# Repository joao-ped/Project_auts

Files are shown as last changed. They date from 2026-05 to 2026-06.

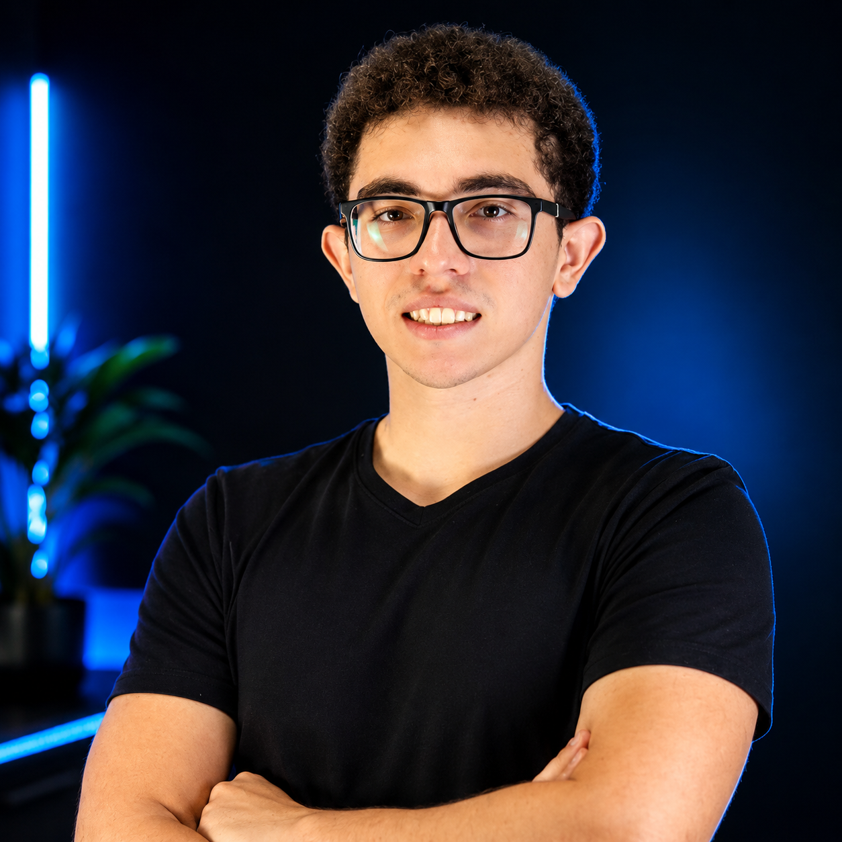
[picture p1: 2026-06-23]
img/Jao_ped.png

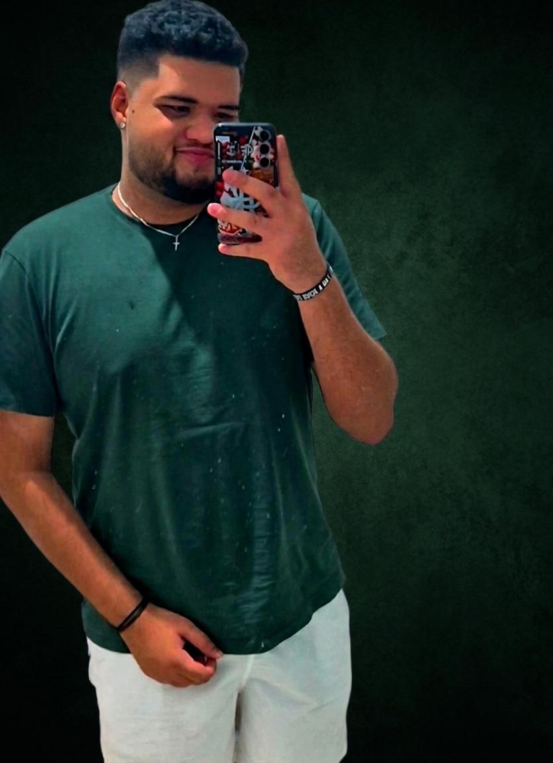
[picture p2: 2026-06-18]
img/Matheus.jpeg

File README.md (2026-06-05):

# Voz Autista v2.0 - Comunicador Assistivo

Dispositivo de comunicacao assistiva de baixo custo para pessoas com autismo que possuem dificuldade na comunicacao verbal. O usuario navega por categorias e palavras usando botoes coloridos, e o dispositivo reproduz o audio correspondente por um alto-falante.

Projeto desenvolvido com Arduino Uno, impressao 3D e componentes acessiveis.

**Site do projeto:** https://joao-ped.github.io/Project_auts/ (apos ativar Pages, veja secao abaixo)

---

## Hospedar no GitHub Pages (passo a passo)

O `index.html` na raiz funciona como pagina inicial e linka para todas as ferramentas. Para ativar:

1. Faca commit e push das mudancas (incluindo `index.html` e `.nojekyll`):
   ```bash
   git add index.html .nojekyll
   git commit -m "Adiciona site index.html + .nojekyll"
   git push origin main
   ```
2. No GitHub, va em **Settings -> Pages** do repositorio
3. Em **Source**, escolha **Deploy from a branch**
4. Em **Branch**, selecione `main` e pasta `/ (root)`, depois **Save**
5. Aguarde 1-2 min e acesse `https://joao-ped.github.io/Project_auts/`

> O arquivo `.nojekyll` (vazio) impede que o Jekyll processe o site - importante para que pastas como `wokwi_simulacao/` e arquivos com underscore funcionem.

Links que ficarao online:
- `/` -> hub (index.html)
- `/apresentacao.html` -> slides
- `/manual_montagem_visual.html` -> manual
- `/simulador.html` -> simulador no navegador
- `/wokwi_simulacao/abrir_no_wokwi.html` -> assistente Wokwi
- `/case_3d/visualizar_case_3d.html` -> viewer 3D

---

## Funcionalidades

- **7 categorias com 35 palavras** - Necessidades, Sentimentos, Acoes, Comidas, Lugares, Pessoas, Saude
- **Frases compostas** - Empilhe ate 5 palavras e fale de uma vez (ex: "Eu quero" + "Beber" + "Agua")
- **Controle de volume** - Potenciometro analogico com ajuste em tempo real
- **Monitoramento de bateria** - Icone no LCD (18650 recarregavel via USB)
- **Feedback tatil** - Motor de vibracao confirma cada acao
- **Modo sleep** - LCD apaga apos 2 min de inatividade para economizar bateria
- **Auto-deteccao I2C** - Funciona com diferentes modulos LCD sem alterar codigo
- **Configuracao facil** - Secao dedicada no codigo para personalizar categorias e palavras

## Como funciona

| Botao | Cor | Funcao |
|---|-----|---|
| Cat+ | Vermelho | Avanca categoria |
| Cat- | Amarelo | Volta categoria |
| Pal+ | Verde | Avanca palavra |
| Pal- | Azul | Volta palavra |
| FALAR | Preto | Press curto = fala / Press longo = adiciona a frase |
| Cat+ & Cat- | Vermelho + Amarelo | Fala a frase composta |
| Pal+ & Pal- | Verde + Azul | Limpa a frase |

## Hardware

### Lista de materiais principais

| Componente | Funcao |
|---|---|
| Arduino Uno R3 | Microcontrolador |
| LCD 16x2 I2C | Display de navegacao |
| DFPlayer Mini + microSD | Reproducao de audio MP3 |
| Alto-falante 8ohm 2W | Saida de som |
| 5x Botoes 12mm (coloridos) | Navegacao e fala |
| Potenciometro 10k linear | Ajuste de volume |
| Motor vibracao coin 10mm | Feedback tatil |
| Transistor 2N2222 + Diodo 1N4148 | Driver do motor |
| Bateria 18650 + Modulo TP4056 | Alimentacao portatil recarregavel |
| Chave deslizante | Liga/Desliga |
| Case impresso 3D | Caixa do dispositivo |

### Pinagem do Arduino

```
D2  -> Botao Vermelho (Cat+)     D10 <- DFPlayer TX
D3  -> Botao Amarelo  (Cat-)     D11 -> 1k -> DFPlayer RX
D4  -> Botao Verde    (Pal+)     A0  <- Potenciometro (volume)
D5  -> Botao Azul     (Pal-)     A1  <- Divisor tensao (bateria)
D6  -> Botao Preto    (FALAR)    A4  -> LCD SDA (I2C)
D7  -> Transistor -> Motor vib.  A5  -> LCD SCL (I2C)
```

### Custo estimado

O custo total dos componentes fica em torno de **~R$ 128**, dependendo do fornecedor. Componentes mais caros: Arduino (~R$35), bateria 18650 (~R$15), LCD I2C (~R$15), impressao 3D (~R$15), DFPlayer (~R$12).

## Estrutura do projeto

```
Project_auts/
|-- voz_autista_maker_code.ino    # Codigo principal (hardware real)
|-- GUIA_IMPLEMENTACAO.md         # Guia completo de montagem e uso
|-- manual_montagem_visual.html   # Manual visual com diagramas SVG interativos
|-- case_3d/
|   |-- case_voz_autista.scad     # Case 3D parametrico (OpenSCAD)
|   |-- exportar_base.scad        # Exportar apenas a base do case
|   |-- exportar_tampa.scad       # Exportar apenas a tampa do case
|   |-- visualizar_case_3d.html   # Visualizador 3D interativo no navegador
|-- wokwi_simulacao/
|   |-- sketch.ino                # Codigo adaptado para simulacao
|   |-- diagram.json              # Circuito do simulador Wokwi
|   |-- wokwi.toml                # Configuracao do Wokwi
|   |-- COMO_USAR.md              # Instrucoes da simulacao
|-- Apresentacao_Voz_Autista.pptx       # Apresentacao v1
|-- Apresentacao_Voz_Autista_v2.pptx    # Apresentacao v2
```

## Simulacao (sem hardware)

O projeto pode ser testado integralmente no simulador **Wokwi** sem precisar de nenhum componente fisico:

1. Acesse [wokwi.com](https://wokwi.com)
2. Crie um novo projeto Arduino Uno
3. Cole o conteudo de `wokwi_simulacao/sketch.ino` no editor
4. Cole o conteudo de `wokwi_simulacao/diagram.json` na aba diagram.json
5. Clique em Play

Na simulacao, o DFPlayer e substituido por um buzzer e o motor de vibracao por um LED verde.

## Cartao SD (hardware real)

Formato: **FAT32** | 7 pastas | 35 arquivos MP3 (voz clara, 1-3s cada)

```
/01/ Necessidades   001.mp3="Eu quero"  002.mp3="Comer"  003.mp3="Beber"  004.mp3="Banheiro"  005.mp3="Dormir"
/02/ Sentimentos    001.mp3="Feliz"     002.mp3="Triste" 003.mp3="Bravo"  004.mp3="Calmo"     005.mp3="Medo"
/03/ Acoes          001.mp3="Brincar"   002.mp3="Ajuda"  003.mp3="Sair"   004.mp3="Parar"     005.mp3="Ir"
/04/ Comidas        001.mp3="Agua"      002.mp3="Suco"   003.mp3="Leite"  004.mp3="Pao"       005.mp3="Fruta"
/05/ Lugares        001.mp3="Casa"      002.mp3="Escola" 003.mp3="Parque" 004.mp3="Medico"    005.mp3="Banho"
/06/ Pessoas        001.mp3="Mamae"     002.mp3="Papai"  003.mp3="Vovo"   004.mp3="Professor" 005.mp3="Amigo"
/07/ Saude          001.mp3="Doi"       002.mp3="Enjoo"  003.mp3="Frio"   004.mp3="Calor"     005.mp3="Cansado"
```

## Case 3D

O case foi projetado em **OpenSCAD** com parametros editaveis. Dimensoes: 170x110x42mm.

- Abra `case_3d/case_voz_autista.scad` no [OpenSCAD](https://openscad.org)
- Ou visualize no navegador abrindo `case_3d/visualizar_case_3d.html`
- Material recomendado: PLA ou PETG

Inclui: berco para bateria 18650, furos para botoes, janela do LCD, grade do alto-falante, abertura para USB/SD/volume/chave.

## Dependencias (Arduino IDE)

Instalar via **Ferramentas > Gerenciar Bibliotecas**:

- `LiquidCrystal_I2C` (por Frank de Brabander)
- `DFRobotDFPlayerMini` (por DFRobot)

## Autonomia

- Bateria 18650 (2600mAh tipica)
- Consumo medio: ~80mA (uso intermitente)
- Autonomia estimada: **~30 horas**

## Licenca

Projeto de codigo aberto para fins educacionais e assistivos.

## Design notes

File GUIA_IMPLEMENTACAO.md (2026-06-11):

# Voz Autista v3.0 - Guia de Implementacao Completo

**Comunicador Assistivo para Pessoas com Autismo**

Versao: 3.0 | Atualizado: Junho 2026

---

## Indice

1. [Visao Geral do Projeto](#1-visao-geral-do-projeto)
2. [Lista de Materiais (BOM)](#2-lista-de-materiais-bom)
3. [Tabela de Pinagem](#3-tabela-de-pinagem)
4. [Esquema de Ligacoes](#4-esquema-de-ligacoes)
5. [Circuito do Motor de Vibracao](#5-circuito-do-motor-de-vibracao)
6. [Circuito de Monitoramento de Bateria](#6-circuito-de-monitoramento-de-bateria)
7. [Estrutura do Cartao SD](#7-estrutura-do-cartao-sd)
8. [Funcionalidades](#8-funcionalidades)
9. [Montagem Passo a Passo (case v3.0)](#9-montagem-passo-a-passo-case-v30)
10. [Upload do Codigo](#10-upload-do-codigo)
11. [Configuracao Facil](#11-configuracao-facil)
12. [Como Usar](#12-como-usar)
13. [Resolucao de Problemas](#13-resolucao-de-problemas)
14. [Notas Tecnicas](#14-notas-tecnicas)

---

## 1. Visao Geral do Projeto

O **Voz Autista** e um dispositivo de comunicacao assistiva (AAC) de baixo custo
(~R$128) para pessoas autistas nao-verbais ou com comunicacao verbal limitada.
O usuario navega por 7 categorias x 5 palavras com botoes coloridos e o
dispositivo reproduz o audio MP3 correspondente.

### O que mudou da v2.0 para a v3.0

**A pinagem dos botoes, LCD, DFPlayer, volume e vibracao NAO mudou.**
As mudancas sao de circuito (valores e fios novos) e de case:

| Mudanca | Por que |
|---|---|
| Divisor da bateria: **10k+10k -> 100k+33k** + capacitor 100nF em A1, lido com a **referencia interna de 1.1V** | Com a 18650 alimentando o Arduino, o VCC *e* a tensao da bateria - medir Vbat/2 contra o proprio VCC dava leitura constante (bug). A referencia interna e absoluta. Bonus: o dreno cai de ~210uA para ~32uA |
| RX do DFPlayer: resistor 1k -> **divisor 1k/2k** | O DFPlayer e logica 3.3V; o divisor entrega 3.3V limpos (recomendacao do datasheet DFR0299) |
| **Capacitor 470uF + 100nF** no VCC/GND do DFPlayer | O modulo tem picos de corrente no inicio de cada faixa que causavam resets/cliques |
| **Fio novo: BUSY do DFPlayer -> D8** | A frase composta espera o MP3 terminar de verdade, em vez de pausa fixa de 1.3s |
| **Boost MT3608** entre a chave e o rail 5V | A 18650 (3.0-4.2V) direto no 5V roda o ATmega fora de spec e deixa o LCD com contraste fraco. O boost entrega 5V estaveis |
| Case v3.0 em cunha, botoes 2+2+1, bateria com tampa de troca | Ver `case_3d/CHANGELOG_V3.md` |

---

## 2. Lista de Materiais (BOM)

| Qtd | Componente | Especificacao | Funcao |
|-----|---|---|---|
| 1 | Arduino Uno R3 | ATmega328P | Microcontrolador principal |
| 1 | LCD 16x2 com modulo I2C | Endereco auto-detectado (0x27/0x3F/0x20/0x38) | Display para navegacao |
| 1 | DFPlayer Mini MP3 | Modulo MP3 com slot microSD | Reproducao de audio |
| 1 | Alto-falante | 8 ohm, 2W, 40mm | Saida de audio |
| 1 | Botao momentaneo 12mm | **Vermelho** | Categoria + (avancar) |
| 1 | Botao momentaneo 12mm | **Amarelo** | Categoria - (voltar) |
| 1 | Botao momentaneo 12mm | **Verde** | Palavra + (avancar) |
| 1 | Botao momentaneo 12mm | **Azul** | Palavra - (voltar) |
| 1 | Botao momentaneo 12mm | **Preto** | FALAR (reproducao) |
| 1 | Resistor 1k ohm | 1/4W | D11 -> RX DFPlayer (perna de cima do divisor) |
| 1 | Resistor 2k ohm | 1/4W | **v3.0** RX DFPlayer -> GND (perna de baixo) |
| 1 | Capacitor eletrolitico 470uF | >= 10V | **v3.0** VCC/GND do DFPlayer (anti-reset) |
| 2 | Capacitor ceramico 100nF | -- | **v3.0** 1x DFPlayer VCC, 1x pino A1 |
| 1 | Potenciometro 10k ohm | Linear (B10K) | Ajuste de volume |
| 1 | Motor de vibracao coin | 10mm, 3-5V | Feedback tatil |
| 1 | Transistor NPN 2N2222 | TO-92 | Driver do motor de vibracao |
| 1 | Diodo 1N4148 | Diodo de sinal | Protecao flyback do motor |
| 1 | Resistor 1k ohm | 1/4W | Base do transistor 2N2222 |
| 1 | Resistor 100k ohm | 1/4W | **v3.0** Divisor da bateria (substitui 10k) |
| 1 | Resistor 33k ohm | 1/4W | **v3.0** Divisor da bateria (substitui 10k) |
| 1 | Bateria 18650 | 3.7V recarregavel | Alimentacao portatil |
| 1 | Modulo TP4056 | Carregador Li-Ion com protecao (DW01A) | Carga via micro-USB |
| 1 | Modulo boost MT3608 | Ajustado para 5.0V | **v3.0** Rail 5V estavel a partir da 18650 |
| 1 | Chave deslizante | 2 posicoes | Liga/Desliga geral |
| 1 | Cartao microSD | FAT32, ate 32GB | Armazenamento dos audios MP3 |
| -- | Fios jumper | Macho-macho e macho-femea | Conexoes |
| 1 | Case impresso 3D v3.0 | Pasta `/case_3d/` (base + tampa + tampa bateria) | Caixa do dispositivo |

**Nota sobre os botoes:** ligados com pull-up interno (INPUT_PULLUP); cada botao
conecta o pino ao GND. Nao precisa resistor externo.

---

## 3. Tabela de Pinagem

| Pino | Componente | Conexao | Observacao |
|---|---|---|---|
| D2 | Botao Vermelho (Cat+) | Botao para GND | INPUT_PULLUP interno |
| D3 | Botao Amarelo (Cat-) | Botao para GND | INPUT_PULLUP interno |
| D4 | Botao Verde (Pal+) | Botao para GND | INPUT_PULLUP interno |
| D5 | Botao Azul (Pal-) | Botao para GND | INPUT_PULLUP interno |
| D6 | Botao Preto (FALAR) | Botao para GND | INPUT_PULLUP interno |
| D7 | Motor vibracao | Via 1k -> base 2N2222 | Flyback 1N4148 no motor |
| **D8** | **DFPlayer BUSY** | **BUSY -> D8 direto** | **NOVO v3.0** - LOW = tocando |
| D10 | DFPlayer TX | TX -> D10 | SoftwareSerial RX |
| D11 | DFPlayer RX | D11 -> 1k -> RX; RX -> 2k -> GND | **ATUALIZADO v3.0** divisor 3.3V |
| A0 | Potenciometro volume | Wiper (centro) | 0-1023 -> volume 0-30 |
| A1 | Divisor da bateria | Juncao 100k (Vbat) / 33k (GND) + 100nF | **ATUALIZADO v3.0** ref interna 1.1V |
| A4 | LCD SDA | Modulo I2C | Barramento I2C dados |
| A5 | LCD SCL | Modulo I2C | Barramento I2C clock |

Pinos livres para expansao: D9, D12, D13, A2, A3.

### Diagrama de pinos do Arduino

```
                     +-----[USB]-----+
                     |               |
                D13 -|               |- D12
                3.3V-|               |- D11 ---> 1k ---> DFPlayer RX ---> 2k ---> GND
                AREF-|               |- D10 <--- DFPlayer TX
 [POT volume]--> A0 -|    ARDUINO    |- D9
 [BAT 100k/33k]> A1 -|     UNO R3    |- D8  <--- DFPlayer BUSY        [NOVO v3.0]
                 A2 -|               |- D7  ---> 1k ---> Base 2N2222
                 A3 -|               |- D6  <--- Botao Preto  (FALAR)
   [LCD SDA] --> A4 -|               |- D5  <--- Botao Azul   (Pal-)
   [LCD SCL] --> A5 -|               |- D4  <--- Botao Verde  (Pal+)
                     |               |- D3  <--- Botao Amarelo(Cat-)
                     |               |- D2  <--- Botao Vermelho(Cat+)
                 5V -|               |- GND
                GND -|               |- GND
                VIN -|               |
                     +---------------+
```

---

## 4. Esquema de Ligacoes

### 4.1 Botoes (todos iguais)

```
Pino Dx ----+---- [Botao] ---- GND
            |
        (pull-up interno ativado por software)
```

| Botao | Cor | Pino | Posicao no case v3.0 |
|---|-----|---|---|
| CAT- | Amarelo | D3 | Fileira de cima, esquerda (simbolo "v") |
| CAT+ | Vermelho | D2 | Fileira de cima, direita (simbolo "^") |
| PAL- | Azul | D5 | Fileira do meio, esquerda (simbolo "<") |
| PAL+ | Verde | D4 | Fileira do meio, direita (simbolo ">") |
| FALAR | Preto | D6 | Embaixo, central, anel maior (balao de fala) |

### 4.2 DFPlayer Mini (ATUALIZADO v3.0)

```
                      +----------+
            D10 <---- | TX       |
 D11 --[1k]--+------> | RX       |     <- divisor 1k/2k: nivel 3.3V
             |        |          |
           [2k]       | VCC -----+--- 5V  (+ 470uF e 100nF para o GND,
             |        |          |         o mais perto possivel do modulo)
            GND       | GND -----+--- GND
                      | SPK1 ----+--- Alto-falante 8ohm 2W (+)
                      | SPK2 ----+--- Alto-falante 8ohm 2W (-)
                      | BUSY ----+--> D8   [NOVO v3.0: LOW = tocando]
                      | SD slot  |  <- microSD FAT32
                      +----------+
```

**Importante:** o eletrolitico de 470uF evita resets do DFPlayer nos picos de
corrente do inicio de cada faixa. Observe a polaridade (perna maior no VCC).

### 4.3 LCD 16x2 I2C

```
  VCC -> 5V | GND -> GND | SDA -> A4 | SCL -> A5
```

### 4.4 Potenciometro de Volume

```
  5V ---[Terminal 1]   A0 ---[Wiper]   GND ---[Terminal 3]
```

### 4.5 Alimentacao completa (ATUALIZADO v3.0)

```
  [Bateria 18650] --- B+/B- --- [TP4056 c/ protecao] --- OUT+ ---[Chave]--- IN+ [MT3608] OUT+ --- 5V do Arduino,
                                       |                                        (ajustado     LCD, DFPlayer, pot,
                                      OUT- ------------------------------------- p/ 5.0V)     motor (rail 5V comum)
                                       |
                                      GND comum (Arduino + LCD + DFPlayer + divisor + emissor 2N2222)
```

**Antes de conectar o Arduino:** alimente o MT3608 e gire o trimpot ate medir
**5.0V** na saida com multimetro. So depois ligue o rail.

**Por que o boost?** A 18650 entrega 3.0-4.2V. Direto no pino 5V, o ATmega328
roda 16MHz abaixo do minimo de 4.5V do datasheet e o LCD HD44780 perde
contraste. O MT3608 (~R$5) resolve os dois problemas e ainda da volume cheio
ao DFPlayer.

---

## 5. Circuito do Motor de Vibracao

(Sem mudancas eletricas na v3.0 - apenas documentacao revisada.)

```
            +5V ----+-------------+
                    |             |
               [Motor coin]   [1N4148]   <- catodo (faixa) no +5V
                    |             |
                    +------+------+
                           |
                       Coletor (C)
                        2N2222          Base (B) --- [1k] --- D7
                       Emissor (E)
                           |
                          GND
```

- Ib = (5 - 0.7) / 1k ~ 4.3mA -> beta forcado ~19 para 80mA: saturacao garantida
- O 1N4148 fica em **antiparalelo com o motor**: catodo (faixa) no +5V, anodo no coletor
- Pinagem do 2N2222 (TO-92, face plana para voce): **E - B - C**

---

## 6. Circuito de Monitoramento de Bateria (ATUALIZADO v3.0)

```
  Bateria (+) -----[R1 = 100k]-----+----------- A1 (Arduino)
                                   |       |
                              [R2 = 33k] [100nF]
                                   |       |
                                  GND     GND
```

### Como funciona (v3.0)

- O divisor entrega `Vbat x 33/133` em A1: 4.2V -> 1.042V; 3.0V -> 0.744V
- O codigo le A1 contra a **referencia interna de 1.1V** (`analogReference(INTERNAL)`),
  que e absoluta - nao depende do VCC variavel da bateria
- ADC ~969 = 100% | ADC ~692 = 0%
- O capacitor de 100nF em A1 compensa a impedancia alta do divisor para o
  sample-and-hold do ADC (fonte: datasheet ATmega328, secao ADC, impedancia
  de fonte recomendada <= 10k)
- Dreno permanente do divisor: ~32uA (era ~210uA com 10k+10k)

> **Atencao:** nao reutilize os resistores de 10k da v2.0 neste divisor - o
> firmware v3.0 espera 100k/33k. Se mudar os valores, recalcule os limites
> 692/969 em `readBattery()`.

---

## 7. Estrutura do Cartao SD

O cartao microSD deve ser formatado em **FAT32**. Sao **7 categorias** com
**5 palavras** cada (35 MP3s):

```
microSD (FAT32)
├── /01/ Necessidades: 001 "Eu quero", 002 "Comer", 003 "Beber", 004 "Banheiro", 005 "Dormir"
├── /02/ Sentimentos:  001 "Feliz", 002 "Triste", 003 "Bravo", 004 "Calmo", 005 "Medo"
├── /03/ Acoes:        001 "Brincar", 002 "Ajuda", 003 "Sair", 004 "Parar", 005 "Ir"
├── /04/ Comidas:      001 "Agua", 002 "Suco", 003 "Leite", 004 "Pao", 005 "Fruta"
├── /05/ Lugares:      001 "Casa", 002 "Escola", 003 "Parque", 004 "Medico", 005 "Banho"
├── /06/ Pessoas:      001 "Mamae", 002 "Papai", 003 "Vovo", 004 "Professor", 005 "Amigo"
└── /07/ Saude:        001 "Doi", 002 "Enjoo", 003 "Frio", 004 "Calor", 005 "Cansado"
```

- Pastas exatamente `01`..`07`; arquivos exatamente `001.mp3`..`005.mp3`
- 44100 Hz, 128 kbps, mono; 1-3 segundos por palavra
- Nao deixe outros arquivos na raiz do cartao

---

## 8. Funcionalidades

### 8.1 Volume por potenciometro (A0)
Leitura a cada 500ms, mapeada para 0-30 e enviada ao DFPlayer.

### 8.2 Auto-deteccao I2C do LCD
Escaneia `0x27`, `0x3F`, `0x20`, `0x38` na inicializacao.

### 8.3 Monitoramento de bateria (A1) - v3.0
Divisor 100k/33k + referencia interna 1.1V (secao 6). Icone no LCD a cada 10s.

### 8.4 Frase composta + fim de audio real (v3.0)

| Acao | Como fazer | Resultado |
|---|---|---|
| Falar palavra | Press **curto** no FALAR | Reproduz o audio |
| Adicionar a frase | Press **longo** no FALAR (>800ms) | Palavra entra no buffer (ate 5) |
| Falar frase | **Cat+ e Cat- juntos** | Fala a sequencia toda |
| Limpar frase | **Pal+ e Pal- juntos** | Esvazia o buffer |

**v3.0:** entre as palavras da frase, o firmware espera o pino **BUSY (D8)**
subir (fim real do MP3) + 250ms de pausa, em vez do delay fixo de 1.3s.
Frases soam naturais com audios de qualquer duracao.

### 8.5 Vibracao (D7)
Motor coin via 2N2222; 60ms a cada acao de botao.

### 8.6 Sleep
LCD apaga apos 2 min sem uso; qualquer botao acorda.

### 8.7 Configuracao facil
Secao demarcada no `.ino` para editar categorias, palavras e tempos.

---

## 9. Montagem Passo a Passo (case v3.0)

> Imprima primeiro: `exportar_base.scad`, `exportar_tampa.scad` e
> `exportar_tampa_bateria.scad` (que inclui o knob do potenciometro e o
> adaptador do botao FALAR). Encaixe tudo A SECO antes de soldar.

### Passo 1: Eletronica de potencia (fora do case)
1. Solde fios na 18650 (ou use suporte com fios) -> B+/B- do TP4056
2. TP4056 OUT+ -> chave deslizante -> IN+ do MT3608; OUT-/GND comum
3. Alimente e ajuste o trimpot do MT3608 ate **5.0V** na saida
4. So entao conecte OUT+ do MT3608 ao pino **5V** do Arduino

### Passo 2: Perfboard do driver e divisores
Em uma perfboard pequena (~20x10mm), monte:
1. 2N2222 + resistor 1k de base + 1N4148 (catodo p/ +5V)
2. Divisor da bateria: 100k (Vbat -> A1) + 33k (A1 -> GND) + 100nF (A1 -> GND)
3. Divisor do DFPlayer: 1k (D11 -> RX) + 2k (RX -> GND)
4. 470uF + 100nF entre VCC e GND do DFPlayer (perto do modulo)

### Passo 3: Fixar na base impressa
1. **Arduino** nos 4 pilares M2.5 (canto esquerdo; USB-B e jack saem pela esquerda)
2. **TP4056** nos clipes (parede esquerda; micro-USB pela abertura)
3. **MT3608** e **perfboard** nos cantos de retencao (fundo esquerdo/tras)
4. **DFPlayer** nos clipes (canto traseiro direito; slot SD pela parede traseira)
5. **Alto-falante** no fundo, ima para cima, borda sob os 3 postes com labio
   (o som sai pela grade no fundo do case)
6. **Motor coin** no suporte anelar (fio pela abertura lateral do anel)
7. **Chave** na moldura recuada da parede traseira (cola quente por dentro)
8. **Potenciometro** no furo da parede direita (porca por fora) + knob impresso

### Passo 4: Botoes na tampa (layout 2+2+1)
1. De cima para baixo: CAT- (amarelo) / CAT+ (vermelho), PAL- (azul) /
   PAL+ (verde), FALAR (preto) embaixo no centro
2. Cada furo tem anel tatil em relevo e canaleta para pintura/anel colorido
3. Pressione o **adaptador Ø18 impresso** sobre o cap do botao preto (FALAR)
4. **LCD**: por dentro da tampa, na face inclinada - 4 parafusos M3
   auto-atarraxantes nos bosses (janela 73x26 para a area visivel)

### Passo 5: Bateria e fechamento
1. Passe o cordao (se for usar) pelas orelhas traseiras (furos de 4mm)
2. Encaixe a tampa (saia interna sobre o rim da base, bumps de clique)
3. 2 parafusos M3: um na frente-direita, um atras-centro
4. Insira a 18650 pelo **fundo** (tampa da bateria com 2 clipes) -
   observe os simbolos +/- em relevo na propria tampa
5. Cole os 4 pes de borracha nos rebaixos do fundo

---

## 10. Upload do Codigo

- Arduino IDE 1.8.x ou 2.x
- Bibliotecas: `LiquidCrystal_I2C` (Frank de Brabander) e
  `DFRobotDFPlayerMini` (DFRobot)
- Placa: Arduino Uno; abra `voz_autista_maker_code.ino` e faca Upload
- O USB-B fica acessivel pela lateral esquerda do case - nao precisa abrir

---

## 11. Configuracao Facil

Edite a secao demarcada no `.ino` (categorias, palavras, tempos).
Detalhes na secao 11 do guia v2.0 permanecem validos; os tempos agora incluem:

```cpp
const int PHRASE_DELAY = 250;  // pausa APOS o fim real do audio (BUSY/D8)
```

---

## 12. Como Usar

1. **Ligar:** chave na posicao ON (recuada na traseira - empurre com a unha)
2. Navegue categorias (fileira de cima) e palavras (fileira do meio)
3. **FALAR** (botao grande de baixo): curto = fala; longo = adiciona a frase
4. Volume: knob estriado na lateral direita
5. Recarga: cabo micro-USB na lateral esquerda (LED vermelho = carregando,
   azul/verde = completo)
6. Troca de bateria: tampa com clipes no fundo - sem abrir o case

---

## 13. Resolucao de Problemas

| Problema | Causa Provavel | Solucao |
|---|---|---|
| LCD nao liga / tela em branco | I2C nao detectado | Verifique SDA (A4) e SCL (A5); ajuste o trimpot de contraste do backpack |
| LCD com contraste fraco mesmo ajustando | Alimentacao abaixo de 5V | Confira a saida do MT3608 (deve ser 5.0V); bateria carregada? |
| DFPlayer nao reproduz | SD em formato errado | FAT32; pastas /01/../07/; arquivos 001.mp3..005.mp3 |
| DFPlayer reseta/clica ao tocar | Falta decoupling | Confirme o 470uF + 100nF no VCC do modulo (470uF com polaridade certa) |
| Frase composta "atropela" as palavras | Fio BUSY solto | Confira BUSY -> D8 (o firmware usa timeout de 8s como fallback) |
| Medidor de bateria nao muda | Divisor errado | Confirme 100k (Vbat->A1) e 33k (A1->GND); meca A1: deve dar Vbat x 0.248 |
| Medidor de bateria sempre cheio/vazio | Resistores trocados entre si | 100k vai no lado da bateria, 33k no lado do GND |
| Volume nao muda | Pot desconectado | 3 fios: 5V, A0 (wiper), GND |
| Motor nao vibra | Driver errado | 2N2222 e E-B-C (face plana p/ voce); 1k na base; 1N4148 catodo no +5V |
| Vibracao continua | Transistor em curto | Troque o 2N2222 |
| Bateria nao carrega | TP4056/cabo | Polaridade da bateria; outro cabo micro-USB |
| Dispositivo desliga sozinho | Bateria fraca | Recarregue (protecao DW01A corta ~2.5V) |
| LCD apaga sozinho | Sleep apos 2 min | Normal - qualquer botao acorda |
| Erro de compilacao | Bibliotecas faltando | Instale LiquidCrystal_I2C e DFRobotDFPlayerMini |
| Audio engasga so na bateria | Boost no limite | Confira o ajuste de 5.0V do MT3608; bateria com carga |

---

## 14. Notas Tecnicas

### Consumo estimado (rail 5V)

| Componente | Corrente tipica |
|---|---|
| Arduino Uno | ~50 mA |
| LCD 16x2 + I2C (backlight) | ~25 mA |
| DFPlayer tocando | ~40 mA (picos de ~200 mA - dai o 470uF) |
| Motor vibracao (60ms) | ~80 mA (breve) |
| Divisor da bateria | ~0.03 mA (v3.0; era 0.21 mA) |
| **Total medio** | **~115 mA no rail 5V** |

### Autonomia com 18650 (via boost)

- O boost converte: corrente na bateria ~ 115mA x 5V / 3.7V / 0.85 (efic.) ~ 183 mA
- 18650 de 2600 mAh -> **~14h de uso continuo**; com sleep e uso intermitente,
  varios dias

### Bibliotecas

| Biblioteca | Versao minima | Funcao |
|---|---|---|
| Wire.h | inclusa | I2C |
| LiquidCrystal_I2C | 1.1.2+ | LCD |
| SoftwareSerial | inclusa | Serial do DFPlayer (D10/D11) |
| DFRobotDFPlayerMini | 1.0.5+ | Controle do MP3 |

### Notas de projeto

- SoftwareSerial em D10/D11 usa pin-change interrupts; nao conflita com nada
  neste projeto (tone() nao e usado no firmware real)
- `analogReference(INTERNAL)` exige descartar a 1a leitura apos a troca de
  referencia (feito em `readBattery()`)
- Pinos livres para expansao: D9, D12, D13, A2, A3
- O LCD trunca nomes com mais de 16 caracteres; frase composta ate 5 palavras

---

**Codigo-fonte:** `voz_autista_maker_code.ino`
**Case 3D v3.0:** pasta `case_3d/` (ver `CHANGELOG_V3.md`)
**Simulacao Wokwi:** pasta `wokwi_simulacao/`
**Manual visual:** `manual_montagem_visual.html`
**Viewer 3D do circuito:** `case_3d/visualizar_circuito_3d.html`

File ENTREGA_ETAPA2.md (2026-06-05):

# Etapa 2 — Atividade 02
## Registro do avanço do desenvolvimento do Projeto Integrador

**Aluno:** João Pedro Tavares Vicente
**Projeto:** Voz Autista v2.0 — Comunicador Assistivo
**Repositório:** https://github.com/joao-ped/Project_auts
**Data de envio:** 05/06/2026 (prazo: 08/06/2026)

---

## 1. Evidências de progresso

O projeto está em fase avançada de desenvolvimento, com toda a parte de **software, documentação, simulação e modelagem 3D concluída**. Falta apenas a montagem física do hardware, que está agendada para a próxima etapa.

### 1.1 Código firmware (Arduino) — CONCLUÍDO
- **Arquivo:** `voz_autista_maker_code.ino` (589 linhas)
- **Funcionalidades implementadas:**
  - 7 categorias com 35 palavras (Necessidades, Sentimentos, Ações, Comidas, Lugares, Pessoas, Saúde)
  - Frases compostas (empilha até 5 palavras)
  - Controle de volume via potenciômetro analógico (A0)
  - Monitor de bateria com ícone no LCD (A1, divisor de tensão)
  - Feedback tátil por motor de vibração (D7, transistor 2N2222)
  - Modo sleep após 2 min de inatividade
  - Auto-detecção do endereço I2C do LCD (0x27, 0x3F, 0x20, 0x38)
  - Seção dedicada de configuração para personalizar categorias

### 1.2 Documentação técnica — CONCLUÍDA
- **README.md** — visão geral do projeto
- **GUIA_IMPLEMENTACAO.md** (26 KB) — guia completo de implementação
- **Manual de Montagem Visual** (`manual_montagem_visual.html`, 125 KB) — 10 etapas com:
  - Plano físico do case 3D (vista superior da base + tampa, em escala 1.6 mm/px)
  - Vistas laterais (esquerda e direita) com cotas de todas as aberturas
  - Esquemático elétrico completo do circuito real v2.0
  - Tabela de pinos
  - Lista de materiais com 18 componentes e quantidades
  - Checklist de testes e seção de troubleshooting

### 1.3 Simulação no Wokwi — CONCLUÍDA
- **Pasta `wokwi_simulacao/`** com:
  - `diagram.json` (18 partes, 27 conexões) — Arduino, LCD I2C, 5 botões, buzzer, LED de vibração, 2 potenciômetros, resistores
  - `sketch.ino` adaptado para simulação (mesmo da pinagem do hardware real)
  - `abrir_no_wokwi.html` — página assistente que copia o circuito para o Wokwi em 3 cliques
  - `COMO_USAR.md` — 5 métodos de import documentados

### 1.4 Simulador no navegador — CONCLUÍDO
- **`simulador.html`** — versão interativa do comunicador que roda no navegador usando Text-to-Speech (Web Speech API). Permite demonstrar o produto sem precisar do hardware físico.

### 1.5 Apresentação — CONCLUÍDA
- **`apresentacao.html`** — slides interativos navegáveis com visão geral, motivação, demonstração, hardware e diferenciais.

### 1.6 Case 3D — MODELO PRONTO PARA IMPRESSÃO
- **`case_3d/case_voz_autista.scad`** (OpenSCAD paramétrico, 456 linhas)
- Dimensões internas: **170 × 110 × 42 mm**
- **Base** com: pilares M3, berço para bateria 18650, suporte do motor de vibração, aberturas para USB Arduino, jack de alimentação, micro-USB TP4056, chave on/off, slot do microSD, furo do potenciômetro
- **Tampa** com: janela do LCD, 5 furos para botões (Ø14 mm), grade do speaker (Ø40 mm), labels em relevo (CAT+, CAT-, PAL+, PAL-, VOZ)
- **`visualizar_case_3d.html`** — viewer 3D no navegador para inspecionar o modelo

### 1.7 Site do projeto (GitHub Pages) — CONCLUÍDO
- **`index.html`** — landing page hub com 6 cards (Apresentação, Manual, Simulador, Wokwi, Case 3D, Código Arduino)
- **`.nojekyll`** configurado para hospedagem
- URL prevista: https://joao-ped.github.io/Project_auts/

### 1.8 Histórico de commits no GitHub
```
1ca7604  Corrige erros no manual: SD card, cores de fios e descrição do circuito
6859cd7  Adiciona orçamento detalhado e circuito esquemático real
a9f2ad4  Adiciona simulador interativo com TTS e melhora apresentação
7869abe  Adiciona apresentação HTML interativa do projeto
8c693d9  v2.0: README completo, case 3D corrigido para impressão, viewer 3D
16ca89a  Commit1
6fbea46  Initial commit
```
(Mais commits serão adicionados nos próximos dias com as melhorias recentes do manual de montagem, do hub index.html e da página assistente do Wokwi.)

### 1.9 Orçamento detalhado — DEFINIDO
Custo total estimado: **R$ 128,00** (componentes principais)

---

## 2. Roadmap — Próximos passos

### 2.1 Curto prazo (junho/2026)
- [ ] **Push do repositório** com `index.html`, `.nojekyll` e melhorias do manual
- [ ] **Ativar GitHub Pages** (Settings → Pages → Source: main / root)
- [ ] **Imprimir o case 3D** (base + tampa) em PLA ou PETG
- [ ] **Comprar os componentes físicos** (Arduino Uno, LCD I2C, DFPlayer Mini, alto-falante, botões, potenciômetro, motor de vibração, bateria 18650, TP4056, transistor 2N2222, diodo 1N4148, resistores, fios, chave slide, parafusos)

### 2.2 Médio prazo (julho/2026)
- [ ] **Montagem do hardware** conforme as 10 etapas do manual visual
- [ ] **Gravação do firmware** no Arduino
- [ ] **Preparação do microSD** com 35 arquivos MP3 organizados em 7 pastas (/01/ a /07/)
- [ ] **Testes em bancada** — validar cada botão, navegação, áudio, vibração, volume, bateria
- [ ] **Ajustes finais no case** se necessário (tolerâncias de impressão)

### 2.3 Longo prazo (agosto/2026 em diante)
- [ ] **Teste com usuários reais** — pessoas autistas não-verbais e suas famílias/cuidadores
- [ ] **Coleta de feedback** — usabilidade, conforto, palavras mais úteis
- [ ] **Iteração do produto** — adaptar categorias e palavras conforme uso real
- [ ] **Documentar resultados** dos testes para apresentação final
- [ ] **Considerar futuras versões** — bluetooth, app companheiro, mais palavras, gravação de voz personalizada

### 2.4 Entregáveis do grupo até a próxima etapa
1. Site no ar (GitHub Pages) com index hub
2. Vídeo curto de demonstração do simulador no navegador
3. Fotos da impressão 3D do case
4. Lista de compra confirmada com fornecedores

---

**Status geral:** Projeto está dentro do cronograma. A fase de software/documentação está 100% concluída, antecipando trabalho que originalmente seria feito junto com a montagem. Isso permite focar na próxima etapa exclusivamente em hardware e testes.

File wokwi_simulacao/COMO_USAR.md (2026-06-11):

# Como Simular o "Voz Autista v3.0" no Wokwi

> **Atalho:** abra `abrir_no_wokwi.html` no navegador deste projeto para uma pagina com
> botoes "Copiar diagram.json" / "Copiar sketch.ino" e o link direto para o Wokwi em branco.

## O que mudou da v2.0 para a v3.0 (simulacao)

| Item | v2.0 | v3.0 |
|---|---|---|
| Bateria em A1 | Potenciometro direto no pino | Pot como "fonte variavel" + **divisor real 100k/33k** + leitura com referencia interna 1.1V (identico ao hardware) |
| Vibracao em D7 | LED + resistor 220 direto | **Driver real**: D7 -> 1k -> base do 2N2222; LED como carga indicadora |
| D11 (DFPlayer RX) | Resistor 1k solto | **Divisor 1k/2k** (nivel 3.3V, igual ao hardware) |
| Labels | Minimos | Labels em portugues por bloco funcional |
| Cores dos fios | Variadas | Padronizadas: vermelho=VCC, preto=GND, amarelo (gold)=digital, verde=SDA, laranja=SCL, roxo=A0, marrom=A1 |

A **pinagem nao mudou** (D2-D6 botoes, D7 vibracao, D10/D11 DFPlayer, A0 volume,
A1 bateria, A4/A5 I2C). O hardware real v3.0 ganhou o fio **BUSY -> D8** (nao usado
na simulacao, pois o buzzer toca de forma sincrona).

## Metodo 1 - Pagina assistente (mais rapido, recomendado)

1. Abra `wokwi_simulacao/abrir_no_wokwi.html` no navegador (clique duplo)
2. Clique em **"Abrir Wokwi (Arduino Uno em branco)"** - abre nova aba
3. No Wokwi, va na aba **diagram.json**, apague tudo
4. Volte a pagina assistente e clique **"Copiar diagram.json"**, cole no Wokwi (Ctrl+V)
5. Va na aba **sketch.ino**, apague, copie do assistente, cole no Wokwi
6. Aperte **Play** verde

## Metodo 2 - Copy/paste manual

1. Acesse [https://wokwi.com](https://wokwi.com)
2. Crie uma conta (gratuita) ou faca login
3. Clique em **"New Project"** > **"Arduino Uno"**
4. No editor de codigo, substitua todo o conteudo pelo arquivo `sketch.ino`
5. Clique na aba **"diagram.json"** (parte inferior do editor)
6. Substitua todo o conteudo pelo arquivo `diagram.json`
7. Clique no botao verde **"Play"**

## Metodo 3 - Links raw do GitHub (para compartilhar com terceiros)

- `diagram.json`: https://raw.githubusercontent.com/joao-ped/Project_auts/main/wokwi_simulacao/diagram.json
- `sketch.ino`:   https://raw.githubusercontent.com/joao-ped/Project_auts/main/wokwi_simulacao/sketch.ino

## Metodo 4 - Gist + URL direta

Crie um Gist publico com os 2 arquivos e abra:
```
https://wokwi.com/projects/new/gist/<GIST_ID>
```

## Componentes da simulacao v3.0

- 1x Arduino Uno
- 1x LCD 16x2 (modo I2C)
- 5x Push Button (vermelho, amarelo, verde, azul, preto)
- 1x Buzzer (substitui DFPlayer + alto-falante - o Wokwi nao tem DFPlayer)
- 1x Transistor NPN 2N2222 + 1x Resistor 1k (base) - driver de vibracao real
- 1x LED verde + 1x Resistor 220 (carga indicadora no lugar do motor coin)
- 2x Potenciometro (volume em A0; "bateria" alimentando o divisor)
- 1x Resistor 100k + 1x Resistor 33k (divisor de tensao da bateria, em A1)
- 1x Resistor 1k + 1x Resistor 2k (divisor do RX do DFPlayer, em D11)
- 1x microSD (somente referencia visual)

> **Nota:** o diodo flyback 1N4148 do motor existe **apenas no hardware real**
> (o Wokwi nao tem o componente e o LED nao gera tensao reversa). O label no
> diagrama lembra disso.

## Conexoes principais

| De | Para | Cor | Funcao |
|---|---|---|---|
| D2..D6 | Botoes (outro lado -> GND) | amarelo  | Navegacao + FALAR |
| D7 | R 1k -> base 2N2222 | amarelo  | Driver de vibracao |
| 5V -> R220 -> LED | coletor do 2N2222 | vermelho | Carga (motor no real) |
| Emissor 2N2222 | GND | preto | Referencia |
| D9 | Buzzer | amarelo  | Audio (so simulacao) |
| D11 | R 1k -> R 2k -> GND | amarelo  | Divisor RX DFPlayer (3.3V)  |
| Pot volume SIG | A0 | roxo | Volume |
| Pot bateria SIG | R 100k -> A1 | marrom | "18650" simulada |
| A1 | R 33k -> GND | marrom | Perna de baixo do divisor |
| LCD SDA / SCL | A4 / A5 | verde/laranja | I2C |

## Como testar o medidor de bateria (v3.0)

1. Rode a simulacao e espere a tela principal
2. Gire o **pot da bateria**:
   - Wiper em ~4.2V -> icone de bateria cheia
   - Wiper em ~3.5V -> icone meio
   - Wiper em ~3.0V -> icone vazio
3. O icone atualiza a cada 10 s (BATTERY_INTERVAL)

> A leitura usa `analogReference(INTERNAL)` (1.1V). O simulador AVR do Wokwi
> suporta a referencia interna; se notar valores estranhos, confira no Serial
> Monitor os valores brutos (4.2V da bateria => ADC ~969).

## Funcionalidades (iguais desde a v2.0)

- **Cat+ / Cat-**: navega categorias | **Pal+ / Pal-**: navega palavras
- **FALAR curto**: fala a palavra | **FALAR longo (>800ms)**: adiciona a frase
- **Cat+ e Cat- juntos**: fala a frase | **Pal+ e Pal- juntos**: limpa a frase
- Sleep apos 2 min; qualquer botao acorda
- 7 categorias x 5 palavras (tons unicos no buzzer para diferenciar)

## Circuito real (hardware) vs simulacao v3.0

| Aspecto | Simulacao (Wokwi) | Hardware Real v3.0 |
|---|---|---|
| Audio | Buzzer em D9, tons | DFPlayer Mini (D10 TX / D11 RX) + falante 2W |
| Fim do audio  | Sincrono (tone + delay) | Pino BUSY do DFPlayer -> D8 |
| Vibracao | 2N2222 + LED como carga | 2N2222 + motor coin + 1N4148 antiparalelo |
| Bateria | Pot -> divisor 100k/33k -> A1 | 18650 -> divisor 100k/33k + 100nF -> A1 |
| Alimentacao | 5V ideal do simulador | 18650 -> TP4056 -> chave -> boost MT3608 |
| Decoupling | Nao necessario | 470uF + 100nF no VCC do DFPlayer |
| SD Card | Visual | microSD FAT32 com 35 MP3s |
| I2C LCD | Sempre 0x27 | Auto-detecta (0x27/0x3F/0x20/0x38) |
| Case | N/A | Impressao 3D v3.0 (cunha, botoes 2+2+1) |

## Estrutura do cartao SD (hardware real)

Identica a v2.0 - 7 pastas `/01/../07/` com `001.mp3..005.mp3`
(ver `GUIA_IMPLEMENTACAO.md`, secao 7).

## Dica: Serial Monitor

Abra o Serial Monitor (115200 baud) para ver categoria/palavra, volume,
frases, sleep/wake e o endereco I2C detectado.

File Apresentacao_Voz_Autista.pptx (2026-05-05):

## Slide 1

Projeto de Prototipacao de Hardware

Voz Autista

Dispositivo de Comunicacao Assistiva para Pessoas com Autismo

Edicao Maker | Plataforma Arduino Uno R3 | Abril 2026

Versão 1.0 — Documento Técnico Completo

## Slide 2

Agenda

Visão Geral do Projeto

01

Objetivo, publico-alvo e funcionalidades

02

Arquitetura do Sistema

Diagrama de blocos e componentes

03

Circuito Elétrico

Esquema de ligacao e lista de materiais

04

Simulação Wokwi

Demonstração do circuito funcionando

05

Case 3D

Design para impressão 3D em OpenSCAD

06

Correções e Melhorias

Problemas encontrados e solucoes

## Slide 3

Visão Geral do Projeto

Objetivo

O Voz Autista é um dispositivo de comunicação assistiva projetado para pessoas com Transtorno do
Espectro Autista (TEA) que apresentam dificuldades na comunicação verbal. O usuário navega por
categorias de palavras e frases pré-definidas e reproduz o áudio correspondente através de um alto-falante.

Público-Alvo

• Crianças e adultos com TEA com
dificuldades de comunicação verbal
• Cuidadores, terapeutas e familiares
que buscam ferramentas de CAA
• Profissionais de saúde e
educação especial

Funcionalidades

• Navegação por 3 categorias:
Necessidades, Sentimentos, Ações
• 5 palavras por categoria com
reprodução de áudio MP3
• Display LCD 16x2 com feedback
visual em tempo real
• 5 botões coloridos com
navegação circular intuitiva

Diferenciais

• Baixo custo (~R$80 em
componentes eletronicos)
• Open-source e replicável
por qualquer maker
• Case imprimível em 3D
com design paramétrico
• Simulação online via Wokwi
para testes sem hardware

Plataforma: Arduino Uno R3 | Áudio: DFPlayer Mini + Alto-falante 8Ω 0.5W | Display: LCD 16x2 I2C

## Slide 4

Arquitetura do Sistema

LCD 16x2 I2C

Categoria + Palavra selecionada

▲ I2C

5 Botões de Navegação

● Vermelho — Categoria ▶

● Amarelo — Categoria ◀

● Verde — Palavra ▶

● Azul — Palavra ◀

● Preto — FALAR

ARDUINO UNO R3

ATmega328P

• Pinos D2-D6: Botões
• Pinos D10-D11: DFPlayer (Serial)
• Pinos A4-A5: LCD (I2C)
• Pino D9: Buzzer (simulação)

▶ Serial

DFPlayer Mini

Módulo MP3 + MicroSD

▶▶▶

▼ Audio

Alto-falante

8Ω 0.5W 40mm

Fluxo de Operação

1. Usuário pressiona botão → 2. Arduino processa entrada (debounce 200ms) → 3. Atualiza LCD com categoria/palavra → 4. Ao pressionar FALAR, DFPlayer reproduz MP3 correspondente pelo alto-falante

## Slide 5

Esquema Elétrico

Diagrama de Ligação

ARDUINO UNO COMPONENTE
────────────────────────────────────
D2 ───── Botao Vermelho ── GND (Cat ▶)
D3 ───── Botao Amarelo ── GND (Cat ◀)
D4 ───── Botao Verde ── GND (Pal ▶)
D5 ───── Botao Azul ── GND (Pal ◀)
D6 ───── Botao Preto ── GND (FALAR)
D10 ───── DFPlayer TX
D11 ─[1kΩ]─ DFPlayer RX
A4 (SDA) ── LCD SDA
A5 (SCL) ── LCD SCL
5V ───── LCD VCC, DFPlayer VCC
GND ───── LCD GND, DFPlayer GND
DFPlayer SPK+ ── Alto-falante (+)
DFPlayer SPK- ── Alto-falante (-)

Lista de Materiais (BOM)

• 1x Arduino Uno R3 (ATmega328P, 5V)
• 1x LCD 16x2 com módulo I2C (0x27)
• 1x DFPlayer Mini (MP3 + MicroSD)
• 1x Cartão microSD (FAT32, até 32GB)
• 1x Alto-falante 8ohm, 0.5W, 40mm
• 5x Botão push momentaneo 12mm
• (vermelho, amarelo, verde, azul, preto)
• 1x Resistor 1kΩ (1/4W, 5%)
• ~20x Cabos jumper macho-macho
• 1x Protoboard 830 pontos (opcional)
•
• Economia: resistores pull-down de 10kΩ
• removidos! O codigo usa INPUT_PULLUP
• interno do Arduino (~47kΩ).

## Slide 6

Simulação no Wokwi

O que é o Wokwi?

Simulador online gratuito de circuitos Arduino.
Permite testar o código e o circuito sem hardware físico.
Acesso: wokwi.com

Adaptações para Simulação

DFPlayer Mini substituído por Buzzer (pino D9).
Cada palavra tem um tom diferente para feedback.
Resistor 1kΩ mantido como referência visual.

Aspecto

Simulação (Wokwi)

Hardware Real

Áudio

Pinos de áudio

Buzzer com tons diferentes

D9 (buzzer)

DFPlayer Mini + alto-falante

D10/D11 (SoftwareSerial)

Cartão SD

Não necessário

microSD FAT32 com MP3s

Categorias programadas:

Resistor 1kΩ

Alimentação

Visual (referência)

Simulada

Entre D11 e DFPlayer RX

USB ou bateria

Necessidades

Eu quero, Comer, Beber, Banheiro, Dormir

Sentimentos

Feliz, Triste, Bravo, Calmo, Assustado

Ações

Brincar, Ajuda, Sair, Entrar, Ouvir

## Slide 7

Case para Impressão 3D

Design Paramétrico em OpenSCAD

• Modelo totalmente paramétrico — ajuste as dimensões conforme necessário
• 2 peças: Base + Tampa (encaixe snap-fit com parafusos M3)
• Material recomendado: PLA ou PETG (~80g de filamento)
• Arquivo .scad editável + visualização 3D interativa em HTML

Dimensões do Case

175 x 115 x 47 mm

170 x 110 x 42 mm

2.5 mm

Raio 8 mm (arredondados)

Externo:

Interno:

Parede:

Cantos:

Base (30mm altura)

• Suportes de montagem para Arduino
Uno (4 pilares M2.5)
• Espaço para DFPlayer Mini e fiação
• Abertura lateral USB (14x12mm)
• Abertura para jack de alimentação
• Abertura para cartão SD do DFPlayer
• 4 pilares de fixação nos cantos (M3)
• Borda de encaixe para a tampa

Tampa (12mm altura)

• Janela para LCD 16x2 (72x25mm)
com rebaixo para PCB
• 5 furos para botões (14mm diâmetro)
com anéis indicadores
• Grade de ventilação circular (40mm)
para o alto-falante
• Suportes internos (cantoneiras)
para fixação do LCD
• Encaixe snap-fit com a base

Configurações de Impressão

• Tecnologia: FDM
• Layer height: 0.2mm
• Infill: 20-25%
• Suportes: Não necessários
• Cor recomendada: Azul claro
• Tempo estimado: ~4-5 horas
• Filamento: ~80g PLA/PETG

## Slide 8

Correções e Melhorias

Durante a análise do projeto original, foram identificados 3 problemas críticos que impediriam o funcionamento correto.

CRÍTICO: Pull-Up vs Pull-Down

Problema:

O código usava INPUT_PULLUP (HIGH) mas o circuito tinha resistores pull-DOWN (10kΩ para GND com botões ligados a 5V). Resultado: botões nunca seriam detectados.

Solução:

Removidos os 5 resistores 10kΩ. Botões agora conectam pino → GND diretamente. O INPUT_PULLUP interno do Arduino é suficiente.

FUNCIONAL: DFPlayer Desativado

Problema:

Todo o código do DFPlayer estava comentado. O dispositivo exibia texto no LCD mas nunca reproduzia áudio — o propósito principal do projeto.

Solução:

Código ativado com biblioteca DFRobotDFPlayerMini. Adicionada detecção de erro e feedback visual no LCD caso o DFPlayer não seja encontrado.

LATENTE: Tipo de millis()

Problema:

A variável lastButtonPressTime usava tipo long (com sinal). millis() retorna unsigned long. Após ~25 dias, overflow causaria comportamento errático.

Solução:

Tipo alterado de long para unsigned long, prevenindo bug após uso prolongado do dispositivo.

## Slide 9

Voz Autista — Resumo

Projeto Completo

Dispositivo funcional de comunicação
assistiva com Arduino, LCD, botões
coloridos e reprodução de áudio MP3.

Case Imprimível

Design paramétrico em OpenSCAD
com visualização 3D interativa.
Pronto para impressão FDM.

Simulação Online

Circuito testável no Wokwi sem
necessidade de hardware físico.
Arquivos prontos para importar.

Documentação

27 páginas de documentação técnica
completa: BOM, esquema elétrico,
código, montagem e testes.

Arquivos Entregues

• case_3d/case_voz_autista.scad — Modelo paramétrico do case (OpenSCAD)
• case_3d/exportar_base.scad / exportar_tampa.scad — Arquivos para exportação STL
• case_3d/visualizar_case_3d.html — Visualização 3D interativa no navegador
• wokwi_simulacao/sketch.ino — Código-fonte Arduino para simulação
• wokwi_simulacao/diagram.json — Circuito montado para importar no Wokwi
• Documento Técnico Completo (PDF, 27 páginas) — Documentação integral do projeto

Obrigado!

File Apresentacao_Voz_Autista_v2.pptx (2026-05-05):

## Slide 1

Voz Autista

Dispositivo de Comunicação Assistiva para Pessoas com Autismo

Edição Maker • Arduino Uno R3 • Abril 2026

Projeto de Prototipação de Hardware — Documento Técnico v1.0

1/9

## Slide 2

Visão Geral

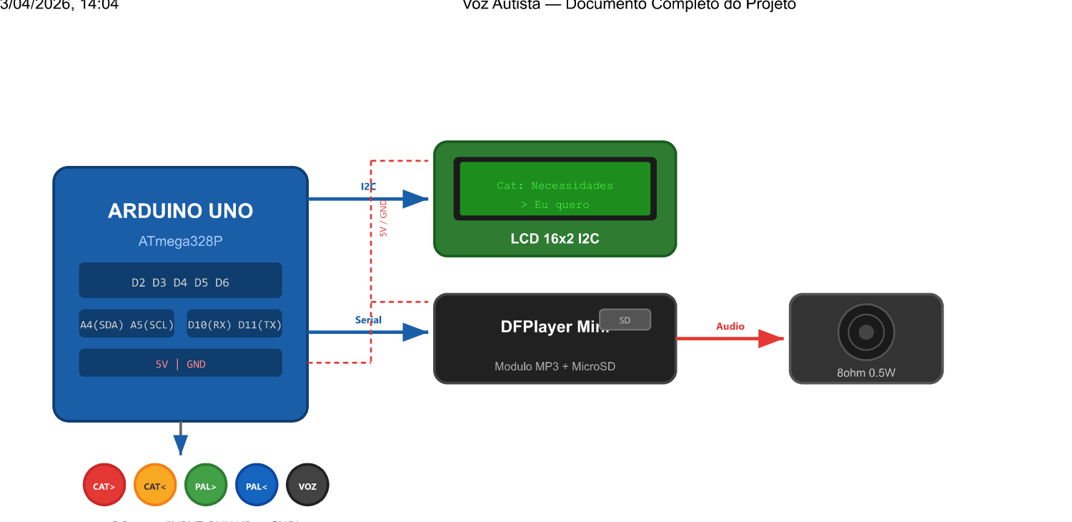
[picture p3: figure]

Arquitetura

Objetivo

O Voz Autista é um dispositivo de comunicação assistiva projetado para pessoas com Transtorno do Espectro Autista (TEA). O usuário navega por categorias de palavras e frases pré-definidas e reproduz o áudio correspondente através de um alto-falante.

Público-Alvo

• Crianças e adultos com TEA
• Cuidadores e terapeutas
• Profissionais de saúde

Funcionalidades

• 3 categorias de palavras
• Reprodução de áudio MP3
• Display LCD 16x2
• 5 botões coloridos

Diferenciais

• Baixo custo (~R$80)
• Open-source e replicável
• Case imprimível em 3D
• Simulação online (Wokwi)

2/9

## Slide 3

Circuito Elétrico

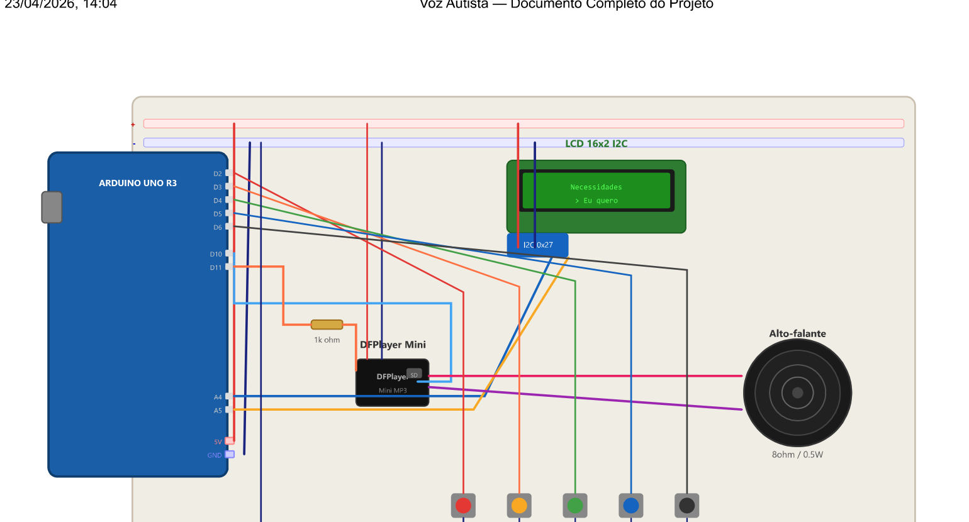
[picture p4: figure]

Lista de Materiais

1x Arduino Uno R3
1x LCD 16x2 I2C (endereço 0x27)
1x DFPlayer Mini MP3
1x Cartão microSD FAT32
1x Alto-falante 8Ω 0.5W 40mm
5x Botão push 12mm (5 cores)
1x Resistor 1kΩ
~20x Cabos jumper

Pinagem Principal

D2-D6 5 Botões → GND
D10-D11 DFPlayer (Serial)
A4-A5 LCD (I2C)
5V / GND Alimentação

Economia: resistores pull-down removidos.
O código usa INPUT_PULLUP interno do Arduino.

3/9

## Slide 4

Simulação no Wokwi

Simulador online gratuito que permite testar o circuito completo sem hardware físico. O DFPlayer Mini foi substituído por um buzzer para simulação de áudio.

Aspecto

Simulação (Wokwi)

Hardware Real

Áudio

Buzzer com tons

DFPlayer Mini + alto-falante

Pinos áudio

Cartão SD

D9 (buzzer)

Não necessário

D10/D11 (SoftwareSerial)

microSD FAT32 com MP3s

Alimentação

Simulada

USB ou bateria

Categorias Programadas

Necessidades

Eu quero, Comer, Beber, Banheiro, Dormir

Sentimentos

Feliz, Triste, Bravo, Calmo, Assustado

Ações

Brincar, Ajuda, Sair, Entrar, Ouvir

4/9

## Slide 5

Case para Impressão 3D

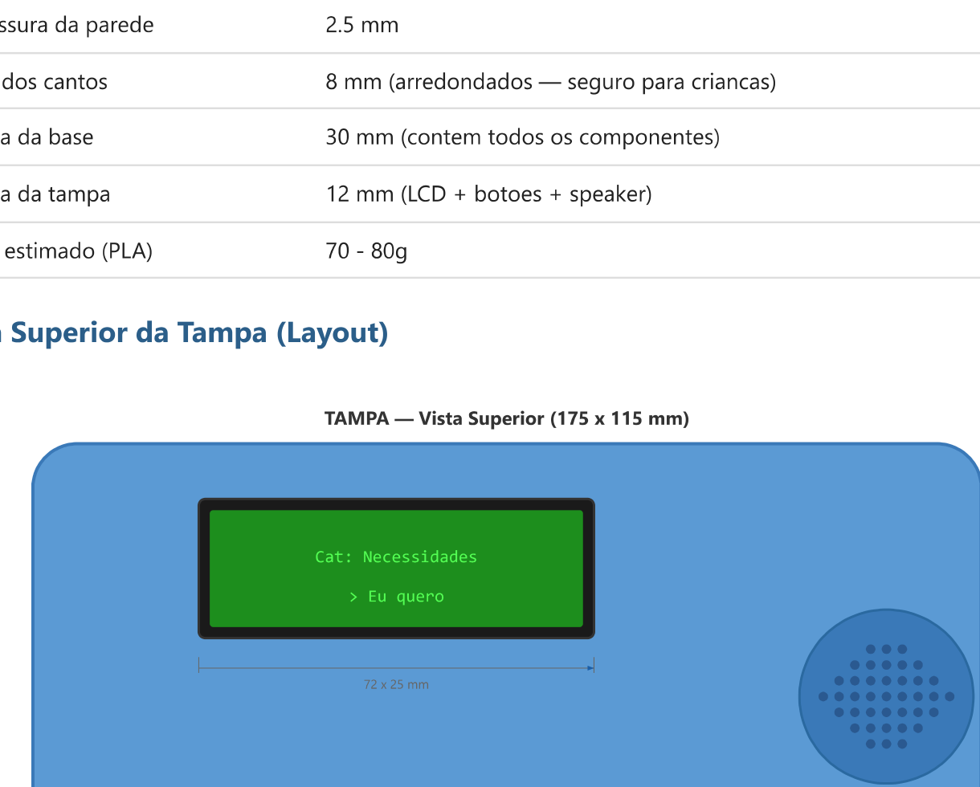
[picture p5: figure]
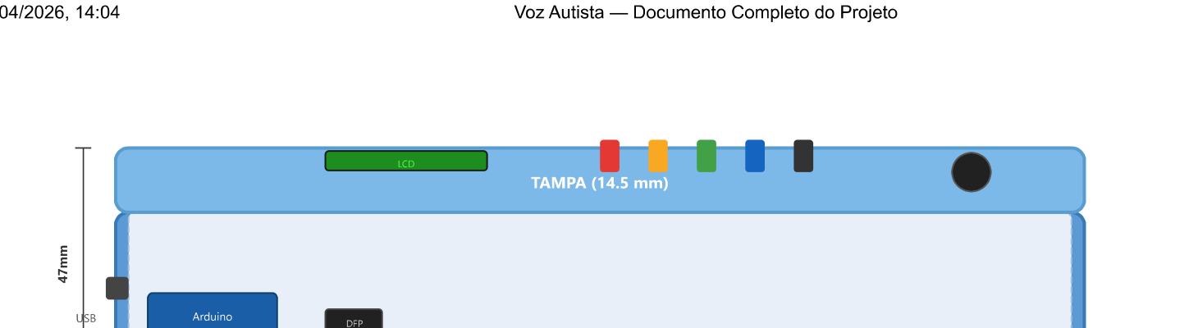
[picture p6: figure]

Dimensões

Externo: 175 x 115 x 47 mm
Interno: 170 x 110 x 42 mm
Parede: 2.5 mm
Peso: ~70-80g (PLA)

Impressão

Material: PLA ou PETG
Layer: 0.2 mm
Infill: 20-25%
Suportes: Não necessários
Tempo: ~5-7 horas

Base

• Suportes para Arduino Uno
• Aberturas USB, jack, SD
• 4 pilares M3 para fixação

Tampa

• Janela LCD 72x25 mm
• 5 furos para botões (14mm)
• Grade alto-falante (40mm)

Design

• Paramétrico (OpenSCAD)
• Visualização 3D em HTML
• Exportação STL inclusa

5/9

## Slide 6

Correções Aplicadas

3 problemas críticos identificados e corrigidos no projeto original.

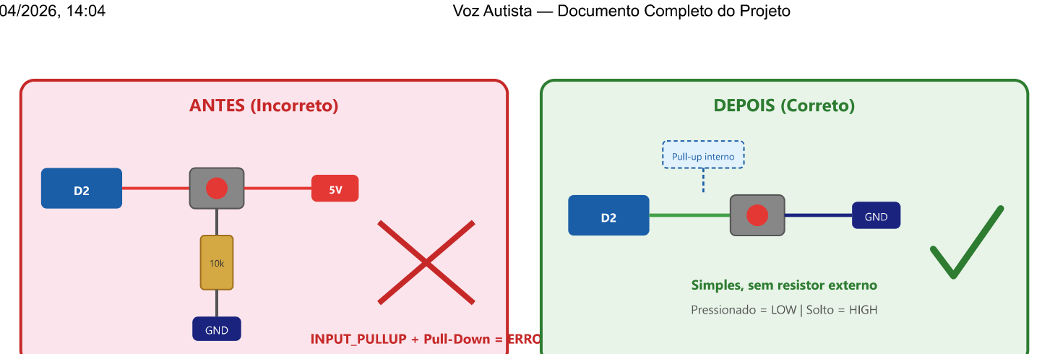
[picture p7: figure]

Pull-Up vs Pull-Down

Botões nunca seriam detectados.
Circuito usava pull-down mas código usava INPUT_PULLUP.

Removidos resistores 10kΩ.
Botões conectam pino → GND.

CRÍTICO

Solução:

DFPlayer Desativado

Código do DFPlayer estava comentado.
Dispositivo mudo — sem áudio.

Ativado com biblioteca DFRobot.
Adicionada detecção de erro.

FUNCIONAL

Solução:

Tipo de millis()

Variável long com sinal.
Overflow após ~25 dias de uso.

Alterado para unsigned long.

LATENTE

Solução:

6/9

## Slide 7

Montagem Passo a Passo

1. Imprimir

• Base + Tampa
• PLA/PETG, 0.2mm
• ~5-7 horas total

2. Eletrônica

• Arduino + LCD
• DFPlayer + Speaker
• 5 Botões coloridos

3. Software

• Arduino IDE
• Upload do sketch
• Bibliotecas I2C/DFP

4. Teste

• LCD + Áudio
• Checklist 13 itens
• Serial Monitor

5. Fechar

• Tampa + Base
• 4x parafusos M3
• Pronto para uso!

Dica: Use o Serial Monitor do Arduino IDE para depuração. O código exibe qual palavra está sendo reproduzida e o ID do arquivo MP3.

7/9

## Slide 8

Arquivos do Projeto

case_3d/

wokwi_simulacao/

Documentação

case_voz_autista.scad

Modelo paramétrico completo do case

sketch.ino

Código-fonte Arduino para simulação

Documento Técnico (PDF)

27 páginas de documentação completa

exportar_base.scad

Arquivo para exportar base em STL

diagram.json

Circuito montado para importar no Wokwi

Visão geral, BOM, esquema elétrico,

exportar_tampa.scad

Arquivo para exportar tampa em STL

wokwi.toml

Configuração do projeto Wokwi

código-fonte, case 3D, montagem e testes

visualizar_case_3d.html

Visualização 3D interativa no navegador

COMO_USAR.md

Instruções de uso passo a passo

8/9

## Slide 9

Voz Autista

Projeto completo, documentado e pronto para replicação.

Hardware

Arduino + LCD + DFPlayer
5 botões + alto-falante

✓

Software

Código Arduino completo
Simulação Wokwi inclusa

✓

Case 3D

Design paramétrico
Pronto para impressão

✓

Documentação

27 páginas técnicas
BOM + esquemas + testes

✓

Obrigado!

9/9

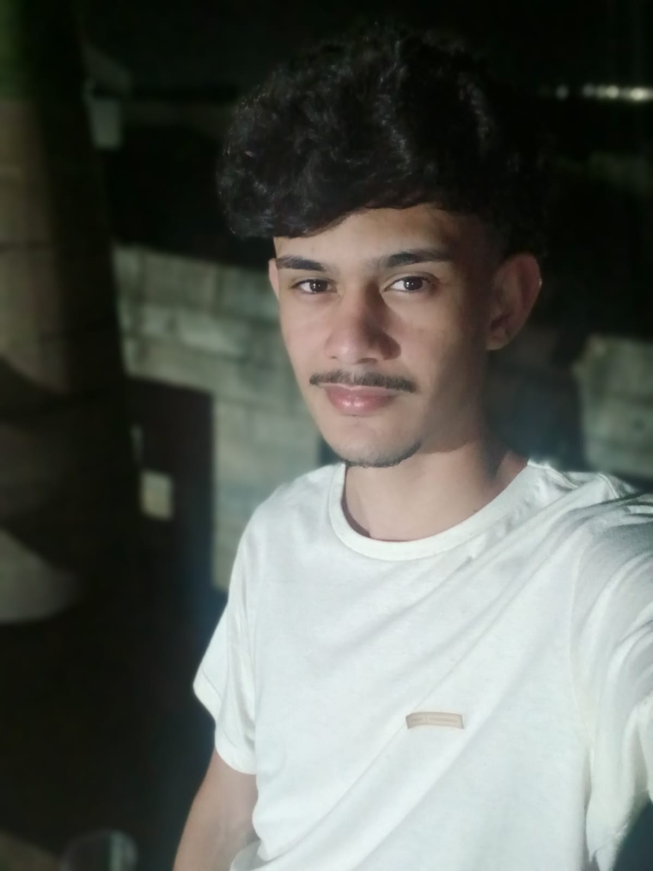
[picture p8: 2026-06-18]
img/victor.jpeg

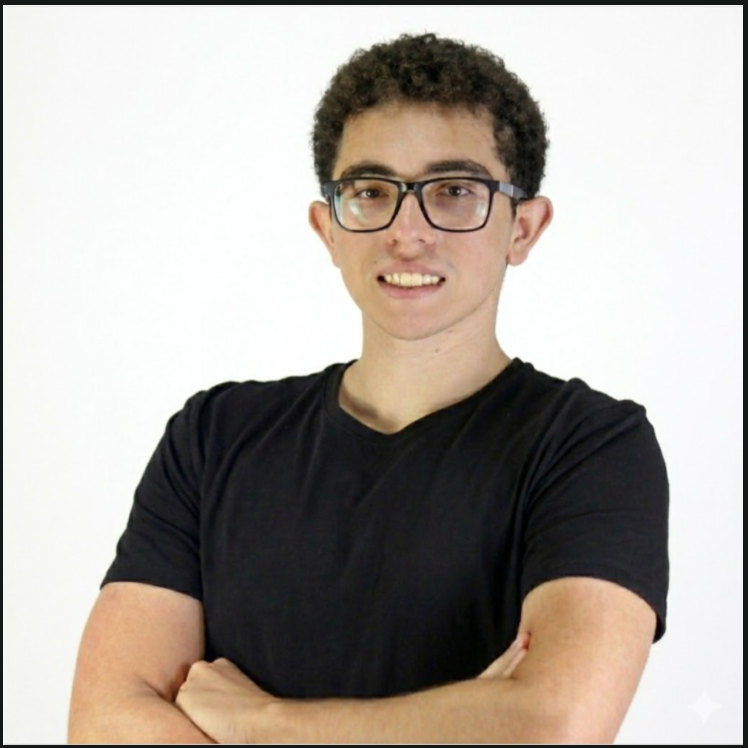
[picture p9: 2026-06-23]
img/JAo.png

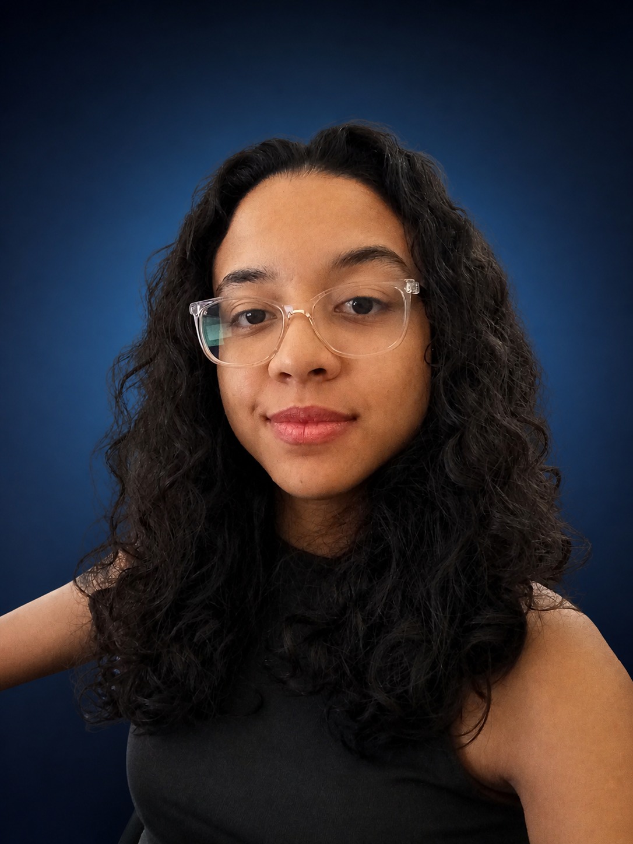
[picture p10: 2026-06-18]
img/ingy.jpeg

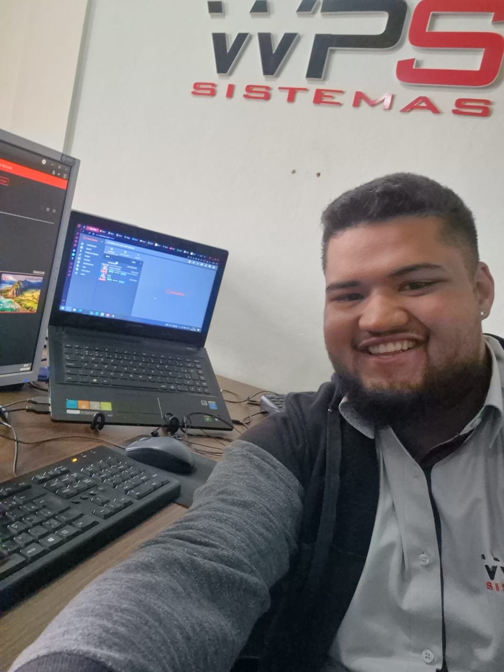
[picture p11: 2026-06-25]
img/Mateus.jpeg

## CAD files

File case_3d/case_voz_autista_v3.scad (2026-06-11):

// ============================================================
// Case "Voz Autista" v3.0 - Comunicador Assistivo (AAC)
// Para impressão 3D (FDM - PLA ou PETG)
// ============================================================
// Abrir com OpenSCAD (https://openscad.org)
// Exportar: F6 (Render) > File > Export as STL
// Use os arquivos exportar_*.scad para gerar cada peça isolada.
// ============================================================
//
// CONFIGURAÇÕES DE IMPRESSÃO RECOMENDADAS:
//   - Material: PLA ou PETG (PETG mais resistente a impacto/calor)
//   - Bico: 0.4 mm | Camada: 0.2 mm | Preenchimento: 25% (giroide)
//   - BASE: imprime em pé (fundo na mesa), SEM suporte.
//   - TAMPA: imprime INVERTIDA (face dos botões na mesa).
//     Necessita suporte APENAS sob a aba inclinada do LCD
//     (cunha de 12°, volume pequeno, remoção fácil).
//   - TAMPA DA BATERIA / KNOB / ADAPTADOR FALAR: sem suporte.
//   - Tempo estimado: ~5h base + ~4h tampa + ~30min miúdos
//
// FORMATO GERAL: "console de mesa" em cunha
//   - Externo: 150 (X) x 100 (Y) x 40 mm na frente,
//     subindo a ~47.7 mm na traseira (face do LCD inclinada 12°).
//   - Cantos arredondados r=10, superfícies pensadas para
//     acabamento fosco (lixar leve ou imprimir com PLA fosco):
//     baixa reflexão e menos estímulo visual (design AAC).
//
// ============================================================
// MAPA INTERNO (vista superior, coordenadas ABSOLUTAS em mm,
// origem no canto externo frente-esquerda; parede = 2.5,
// portanto o interior vai de (2.5, 2.5) a (147.5, 97.5)):
//
//  y=100 ┌─[chave on/off]────[slot SD DFPlayer]────────────────┐
//        │(o) x22-36, recuada       x101-115            (o)    │ <- orelhas cordão Ø4
//        │ ┌────────┐┌───────┐┌─────┐  ╔═════════╗ ┌─────────┐ │    (externas, traseira)
//        │ │PERFBOARD││MT3608 ││motor│  ║   LCD   ║ │DFPlayer │ │
//        │ │ driver  ││boost  ││coin │  ║ (pende  ║ │  Mini   │ │
//   y=80 │ │10-30,   ││34-52, ││Ø10  │  ║da tampa ║ │97.5-118 │ │  ┌──────────┐
//        │ │80-90    ││80-91  ││52,72│  ║inclinada║ │77-97.5  │ │  │ BATERIA  │
//        ├─┴────────┐└───────┘└─────┘  ║  12°)   ║ └─────────┘ │  │  18650   │
//        │ TP4056   │                  ╚═════════╝             │  │ x122-143 │
//   y=60 │ 6.5-32.5,│   ··· tampa começa a inclinar em y=64 ···│  │ y24.5-92.5│
//        │ 62.5-79.5│  ╭─────────────────╮                     │  │          │
//        ├──────────┘  │   ALTO-FALANTE  │  [CAT-]    [CAT+]   │  │ (tampa de│
//        │┌────────────┤   Ø40 no FUNDO  │   x63.5     x91.5   │  │  troca no│
//   y=40 ││ ARDUINO UNO│   grade p/baixo │        y=54.5       │  │  FUNDO,  │
//  [USB] ││ x6.5-75.1  │   centro        │  [PAL-]    [PAL+]   │  │  2 clipes)│
//  [jack]││ y5.5-58.9  │   (97.5, 40.5)  │   x63.5     x91.5   │  └──────────┘
//        ││ pilares 3mm╰────────┬────────╯        y=35         │ <- pot. volume
//  [µUSB]││ topo z=18           │                              │    knob Ø20
//   y=20 │└─────────────────────┘     ( FALAR Ø14, anel Ø24 )  │    y=15.5, z=20
//        │                              x77.5  y=17.5          │
//   y=0  └──────────────────────────────────────────────────────┘
//         x=0                                              x=150
//
// ALTURAS (z, a partir do fundo externo):
//   fundo 0-2.5 | piso interno 2.5 | base até 26.5 | tampa 26.5-40 (frente)
//   topo inclinado 40 -> 47.7 (y=64 -> y=100)
//   Arduino: pilar 3 + placa c/ USB 15 = topo z 20.5
//   Botões: corpo 15 mm pendurado da tampa = z 25 -> 40 (frente)
//   Bateria: Ø18.6 deitada no poço, topo z ~21.5
//   LCD + backpack I2C: pende 25 mm da face inclinada (livre por baixo)
//
// VALIDAÇÃO DE COLISÕES: ver CHANGELOG_V3.md (tabela completa).
// ============================================================

// ===================== PARÂMETROS GERAIS =====================

wall       = 2.5;    // Espessura de parede
ext_w      = 150;    // Largura externa (X)
ext_d      = 100;    // Profundidade externa (Y)
front_h    = 40;     // Altura externa na frente (face dos botões)
slope_ang  = 12;     // Inclinação da face do LCD (graus)
slope_y0   = 64;     // Y absoluto onde o topo começa a subir
corner_r   = 10;     // Raio dos cantos (acessibilidade: sem arestas)
tolerance  = 0.3;    // Folga de encaixe entre peças

base_h     = 26.5;   // Altura externa da base (fundo 2.5 + parede 24)
rear_h     = front_h + (ext_d - slope_y0) * tan(slope_ang); // ~47.65

eps        = 0.1;    // Offset anti z-fighting em booleans
$fn        = 48;

// ===================== COMPONENTES (coordenadas ABSOLUTAS) =====================

// --- Arduino Uno R3 ---
ard_x = 6.5;  ard_y = 5.5;          // Canto da PCB
ard_w = 68.6; ard_d = 53.4;
// Furos de montagem CANÔNICOS do Uno R3 (relativos ao canto da PCB)
// Fonte: desenho mecânico oficial Arduino Uno (spacing 1.27mm grid)
ard_holes = [[15.24, 2.54], [15.24, 50.80], [66.04, 7.62], [66.04, 35.56]];
ard_pillar_h = 3;                    // Pilar baixo: deixa folga p/ botões acima

// Aberturas lateral ESQUERDA (Arduino) - centro Y e tamanhos
usb_yc  = ard_y + 40;  usb_w = 14;  usb_h = 13; usb_z = 6;   // USB-B
jack_yc = ard_y + 10;  jack_w = 13; jack_h = 12; jack_z = 5; // Jack 5.5/2.1

// --- LCD 16x2 + backpack I2C (montado na face inclinada da tampa) ---
lcd_win_w = 73;  lcd_win_h = 26;     // Janela (ativa real: 71.4 x 24.3)
lcd_pcb_w = 81;  lcd_pcb_h = 37;     // Rebaixo p/ PCB 80x36
lcd_cx    = 75;                       // Centro X da janela (centro do case)
lcd_s0    = 5;                        // Início da janela ao longo da rampa (mm)
lcd_hole_dx = 75; lcd_hole_dy = 31;  // Furos de montagem do LCD (Ø3)

// --- DFPlayer Mini (SD pela parede TRASEIRA) ---
dfp_x = 97.5; dfp_y = 77; dfp_w = 20.5; dfp_d = 20.5;
sd_w = 14; sd_z = 4; sd_h = 5.5;     // Abertura do cartão SD

// --- Botões: layout 2+2+1 (acessibilidade: FALAR maior e isolado) ---
btn_hole_d   = 14;     // Furo p/ botão 12mm (folga)
btn_ring_w   = 1.5;    // Largura do anel tátil
btn_ring_h   = 1.2;    // ALTURA do anel tátil (alto: evita toque acidental)
btn_falar    = [77.5, 17.5];                       // FALAR (preto) - Ø anel 24
btn_pal      = [[63.5, 35], [91.5, 35]];           // PAL- (azul) | PAL+ (verde)
btn_cat      = [[63.5, 54.5], [91.5, 54.5]];       // CAT- (amarelo) | CAT+ (vermelho)
relief_h     = 0.8;    // Altura dos pictogramas/textos em relevo

// --- Alto-falante 40mm (montado no FUNDO, grade para baixo) ---
spk_cx = 97.5; spk_cy = 40.5; spk_d = 40; spk_t = 5.5;

// --- Bateria 18650 (poço vertical à direita, tampa de troca no fundo) ---
bat_x0 = 122;  bat_x1 = 143;     // Cavidade (21 mm p/ Ø18.6 + folga)
bat_y0 = 24.5; bat_y1 = 92.5;    // Cavidade (68 mm p/ 65 + terminais)
bat_wall = 2.5;                  // Parede do poço
bat_wall_h = 21;                 // Altura das paredes do poço
door_open = [124, 28, 17, 60];   // Abertura no piso [x, y, w, d]
door_rec  = [121, 25, 23, 66];   // Rebaixo externo p/ tampa [x, y, w, d]
door_rec_depth = 1.3;            // Profundidade do rebaixo
door_t    = 1.2;                 // Espessura da tampa da bateria

// --- TP4056 (micro-USB pela parede esquerda) ---
tp_x = 6.5; tp_y = 62.5; tp_w = 26; tp_d = 17;
tp_usb_w = 10; tp_usb_z = 4; tp_usb_h = 5;

// --- MT3608 boost (v3.0: rail 5V estável a partir da 18650) ---
mt_x = 34.5; mt_y = 80.5; mt_w = 17; mt_d = 11;

// --- Perfboard do driver (2N2222 + 1N4148 + resistores + caps) ---
pb_x = 10.5; pb_y = 80; pb_w = 20; pb_d = 10;

// --- Motor de vibração coin ---
vib_cx = 52.5; vib_cy = 72.5; vib_d = 10; vib_t = 3;

// --- Potenciômetro de volume (parede DIREITA, frente) ---
pot_yc = 15.5; pot_zc = 20; pot_hole_d = 7.5;

// --- Chave on/off (parede TRASEIRA, recuada em moldura) ---
sw_x0 = 22.5; sw_w = 13.4; sw_z0 = 12; sw_h = 5.6;
sw_guard = 2.5;                  // Moldura externa que recua a chave

// --- Furos do cordão (orelhas externas traseiras, reforçadas) ---
lan_hole_d = 4.5;
lan_tabs_x = [14, 136];          // Centros X das orelhas
lan_tab_w = 14; lan_tab_d = 8; lan_tab_t = 5;
lan_tab_z = 32;                  // Altura do centro da orelha

// --- Pés de borracha (rebaixos no fundo) ---
foot_d = 10; foot_depth = 1.5; foot_inset = 14;

// --- Parafusos da tampa (2x M3, diagonais) ---
screw_pos = [[139.5, 10.5], [70, 93]];
screw_r = 1.7; screw_pillar_r = 4;

// ===================== QUAL PEÇA RENDERIZAR =====================

render_base         = true;
render_lid          = true;
render_battery_door = true;
render_knob         = false;  // Knob estriado Ø20 do potenciômetro
render_falar_cap    = false;  // Adaptador Ø18 p/ o botão FALAR

explode = 25;  // Separação visual entre base e tampa (0 = montado)

// ===================== MÓDULOS BÁSICOS =====================

// Retângulo arredondado 2D
module rounded_rect(w, d, r) {
    offset(r) square([w - 2*r, d - 2*r]);
}
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

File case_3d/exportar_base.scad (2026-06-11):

// Arquivo auxiliar para exportar APENAS a BASE (v3.0) como STL
// Abra no OpenSCAD > F6 (Render) > File > Export as STL
//
// A base imprime na orientação em que aparece (fundo na mesa),
// SEM suporte.

include <case_voz_autista_v3.scad>

// No OpenSCAD, a última atribuição no escopo raiz prevalece.
render_base         = true;
render_lid          = false;
render_battery_door = false;
render_knob         = false;
render_falar_cap    = false;
explode = 0;

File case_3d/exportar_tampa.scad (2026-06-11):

// Arquivo auxiliar para exportar APENAS a TAMPA (v3.0) como STL
// Abra no OpenSCAD > F6 (Render) > File > Export as STL
//
// A tampa é exportada INVERTIDA (face dos botões na mesa) para que
// os anéis táteis, pictogramas e furos saiam limpos.
//
// ATENÇÃO - SUPORTE: como o topo é em cunha (face do LCD a 12°),
// ao imprimir invertida a aba inclinada fica suspensa (~8mm no
// ponto mais alto). Habilite suporte "touching buildplate" apenas
// nessa região (fatiador: pintar suporte sob a rampa traseira).
// O restante da peça NÃO precisa de suporte.

include <case_voz_autista_v3.scad>

render_base         = false;
render_lid          = false;
render_battery_door = false;
render_knob         = false;
render_falar_cap    = false;
explode = 0;

// Renderiza a tampa de cabeça para baixo, apoiada na face frontal plana
translate([0, 0, rear_h + 1])
mirror([0, 0, 1])
lid();

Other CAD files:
case_3d/exportar_tampa_bateria.scad
case_3d/case_voz_autista.scad

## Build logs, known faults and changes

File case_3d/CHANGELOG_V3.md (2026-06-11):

# CHANGELOG — Case Voz Autista v2.0 → v3.0

Redesign integrado: case + circuito + simulação + manual + viewer 3D.
Arquivos novos/alterados estão listados no fim.

---

## 1. Bugs do case v2.0 corrigidos

| # | Bug (referência ao `case_voz_autista.scad` v2.0) | Correção na v3.0 |
|---|---|---|
| 1 | **Colisão Arduino × bateria**: Arduino em (5,5) ocupando X:5–74 / Y:5–59 (linhas 68–72) e berço da 18650 centrado em (55,55) com 67 mm de comprimento (linhas 115–119) — a bateria atravessava fisicamente o footprint do Arduino | Bateria movida para **poço vertical à direita** (X:122–143, Y:24.5–92.5), com **tampa de troca no fundo** (2 clipes cantilever). Zero sobreposição (tabela na seção 5) |
| 2 | **Altura interna apertada**: base de 30 mm (linha 62) para Arduino com USB-B de 15 mm + cabos + botões de corpo 15 mm | Frente com **35 mm internos** (40 externos) e traseira em cunha até ~48 mm. Botões ficam sobre o Arduino com 2 mm de folga sobre o ponto mais alto (USB-B), que fica fora da zona de botões |
| 3 | **Furos do Arduino imprecisos**: (14,2.5), (66,7.6), (66,35.6), (15.2,50.8) (linhas 432–437) | Coordenadas **canônicas** do Uno R3: (15.24,2.54), (15.24,50.80), (66.04,7.62), (66.04,35.56) |
| 4 | **Janela do LCD plana** (tampa horizontal, linhas 497–503) | Face do LCD **inclinada 12°** (estilo console de mesa), janela 73×26 na rampa, PCB fixada por 4 bosses perpendiculares à rampa |
| 5 | **Botões em linha única** com labels pequenos (linhas 505–535) | Layout **2+2+1**: par CAT em cima, par PAL no meio, FALAR sozinho embaixo, central e maior (anel Ø24 + adaptador impresso Ø18). Anéis táteis de **1.2 mm** (eram 0.5) e pictogramas em relevo (setas, balão de fala) |
| 6 | Speaker na tampa, junto dos botões (linhas 511–513, 546–549) | Speaker no **fundo** (grade para baixo, pés de borracha afastam da mesa) — não abafa quando o aparelho é segurado pela frente e libera a face superior |

## 2. Mudanças no circuito (pinagem MANTIDA)

Nenhum pino mudou de função. Diff de circuito:

| Item | v2.0 | v3.0 | Justificativa |
|---|---|---|---|
| Divisor da bateria (A1) | 10k + 10k | **100k + 33k + 100nF**, leitura com `analogReference(INTERNAL)` (1.1V) | **Bug real**: com a 18650 no rail, AVcc = Vbat → leitura ratiométrica constante. Ref. interna é absoluta. Dreno cai de ~210µA p/ ~32µA. Limites novos no firmware: ADC 692 (3.0V) a 969 (4.2V) |
| RX do DFPlayer (D11) | 1k em série | **1k série + 2k → GND** | DFPlayer é lógica 3.3V; divisor entrega nível correto (datasheet DFR0299) |
| Decoupling DFPlayer | — | **470µF + 100nF** no VCC/GND do módulo | Picos de corrente no início de faixa causam reset/clique (problema notório do módulo) |
| BUSY do DFPlayer | não ligado | **BUSY → D8** (fio novo) | Frase composta espera o fim real do MP3 (antes: delay fixo 1.3s). `PHRASE_DELAY` virou pausa de 250ms pós-áudio |
| Alimentação | 18650 → TP4056 → chave → VIN/5V | 18650 → TP4056 → chave → **MT3608 (5.0V)** → rail 5V | 3.0–4.2V direto: ATmega a 16MHz fora de spec (<4.5V) e LCD HD44780 sem contraste. Único módulo adicionado (~R$5) |
| Driver do motor (D7) | 2N2222 + 1k + 1N4148 | mantido | Conferido: Ib≈4.3mA, beta forçado ≈19 p/ 80mA — saturação OK; 1N4148 antiparalelo, catodo no +5V |

Pinos livres após v3.0: D9, D12, D13, A2, A3.

## 3. Decisões de design (acessibilidade autista / AAC)

- **Anéis táteis altos (1.2 mm)** ao redor de cada botão: guiam o dedo e reduzem toques acidentais (baixa coordenação motora).
- **FALAR dominante**: central inferior, anel Ø24, adaptador impresso Ø18 sobre o cap de 12 mm — é o botão mais usado.
- **Pictogramas em relevo** (▲▼ CAT, ◀▶ PAL, balão de fala FALAR): leitura tátil + visual, sem depender de cor.
- **Canaleta de 0.6 mm** no topo de cada anel para pintura acrílica ou anel de filamento colorido (FDM mono-cor não imprime colorido).
- **LCD a 12°**: legível com o aparelho sobre a mesa ou no colo, estilo console.
- **Cantos r=10 e formas arredondadas**, superfícies pensadas p/ acabamento fosco: menos reflexo e estímulo visual.
- **Chave recuada** em moldura externa: não desliga sem querer.
- **Orelhas traseiras reforçadas** com furos Ø4: cordão de pescoço ou alça de pulso.
- **Tampa de bateria no fundo** com clipes e símbolos +/− em relevo: cuidador troca a 18650 sem abrir o case.
- **Nervuras** nas paredes longas + paredes de 2.5 mm: o case vai cair no chão (uso real por crianças).
- **USB-B, jack e micro-USB pela esquerda**: upload e recarga sem desmontar.
- **Selo "VOZ AUTISTA v3.0"** em baixo-relevo no fundo + área lisa rebaixada para etiqueta com o nome do usuário.

## 4. Medidas finais

| Medida | Valor |
|---|---|
| Externo (L×P) | 150 × 100 mm |
| Altura frente / traseira | 40 mm / ~47.7 mm (rampa 12° a partir de y=64) |
| Interno (L×P) | 145 × 95 mm |
| Altura interna na frente | 35 mm |
| Parede / piso / topo | 2.5 mm |
| Divisão base/tampa | z = 26.5 mm |
| Cantos | r = 10 mm |
| Furos botões / anel FALAR | Ø14 / anel Ø24 |
| Janela LCD | 73 × 26 mm (ativa 71.4 × 24.3) |
| Tampa da bateria | 22.4 × 65.4 mm, 2 clipes |
| Orelhas cordão | furo Ø4.5, tab 14×8×5 |

## 5. Validação de colisões (coordenadas absolutas, mm)

| Componente | x | y | z | Folga crítica verificada |
|---|---|---|---|---|
| Arduino Uno (c/ USB) | 6.5–75.1 | 5.5–58.9 | 3–20.5 | botões começam em z=25 ✓; USB-B (alto) fora da zona de botões ✓ |
| Bateria 18650 (poço) | 122–143 | 24.5–92.5 | 2.5–21.5 | LCD termina em x=115.5 ✓; botões terminam em x≈101 ✓ |
| TP4056 | 6.5–32.5 | 62.5–79.5 | 2.5–7 | Arduino termina em y=58.9 ✓ |
| MT3608 | 34.5–51.5 | 80.5–91.5 | 2.5–7 | motor (x45–55, y65–75) não alcança ✓ |
| Perfboard driver | 10.5–30.5 | 80–90 | 2.5–13 | TP4056 termina em y=79.5 ✓ |
| DFPlayer | 97.5–118 | 77–97.5 | 2.5–10.5 | LCD pende até z≈15 nessa região ✓ |
| Alto-falante | 77.5–117.5 (corpo) | 20.5–60.5 | 2.5–8 | Arduino até x=75.1 ✓; poço da bateria em x=119.5 ✓ (postes a 118.7) |
| Motor coin | 47.5–57.5 | 67.5–77.5 | 2.5–6.5 | sob o LCD (folga >8) ✓ |
| Potenciômetro | 138.5–147.5 | 9.5–21.5 | 15–24 | parede do poço começa em y=22 ✓ |
| Chave | 22.5–36 | 92–95 | 12–17.6 | pilar de parafuso em (70,93) ✓ |
| LCD (pendurado da rampa) | 35–115 | ~64–95 | ≥12.5 do piso interno | tudo abaixo tem ≤8 mm ✓ |
| Botões (corpo) | spots Ø13 | — | 22.5–37.5 | topo do Arduino 20.5 ✓ (2 mm) |

## 6. Impressão — como reimprimir / o que reusar

**Reusar da v2.0:** nada das peças impressas (geometria mudou toda). Parafusos M2.5/M3, pés de borracha e toda a eletrônica são reaproveitados (exceto os 2 resistores de 10k, substituídos por 100k+33k).

**Imprimir (PLA ou PETG, bico 0.4, camada 0.2, 25% giroide):**

| Peça | Arquivo | Orientação | Suporte |
|---|---|---|---|
| Base | `exportar_base.scad` | fundo na mesa | NÃO |
| Tampa | `exportar_tampa.scad` | invertida (botões na mesa) | SÓ sob a rampa do LCD (cunha de ~8 mm; pinte o suporte no fatiador) |
| Tampa bateria + knob + adaptador FALAR | `exportar_tampa_bateria.scad` | deitados | NÃO |

**Validação pendente:** o `.scad` foi verificado por análise de coordenadas (tabela acima), mas **não foi renderizado** nesta máquina (OpenSCAD não instalado). Antes de fatiar: abra no OpenSCAD, F6, e confira visualmente encaixes e a rampa do LCD. Ajuste `tolerance` (0.3) se os encaixes ficarem justos na sua impressora.

## 7. Coerência entre artefatos

Pinagem/circuito v3.0 aplicados de forma idêntica em:

- `voz_autista_maker_code.ino` — firmware real (divisor novo, ref 1.1V, BUSY/D8, fim de áudio real)
- `wokwi_simulacao/sketch.ino` + `diagram.json` — divisor real 100k/33k, driver 2N2222 real, labels PT, cores padronizadas
- `wokwi_simulacao/COMO_USAR.md` — diferenças simulação × hardware
- `manual_montagem_visual.html` — manual v3.0 com SVGs novos e badges "ATUALIZADO v3.0"
- `GUIA_IMPLEMENTACAO.md` — BOM, pinagem, esquemas ASCII e montagem no case v3.0
- `case_3d/case_voz_autista_v3.scad` (+ 3 exportadores) — case novo
- `case_3d/visualizar_circuito_3d.html` — viewer 3D interativo (Three.js) com os cabos da pinagem v3.0

Convenção de cores (todos os artefatos): vermelho=VCC, preto=GND, amarelo=digital, verde=SDA, laranja=SCL, roxo=A0, marrom=A1.

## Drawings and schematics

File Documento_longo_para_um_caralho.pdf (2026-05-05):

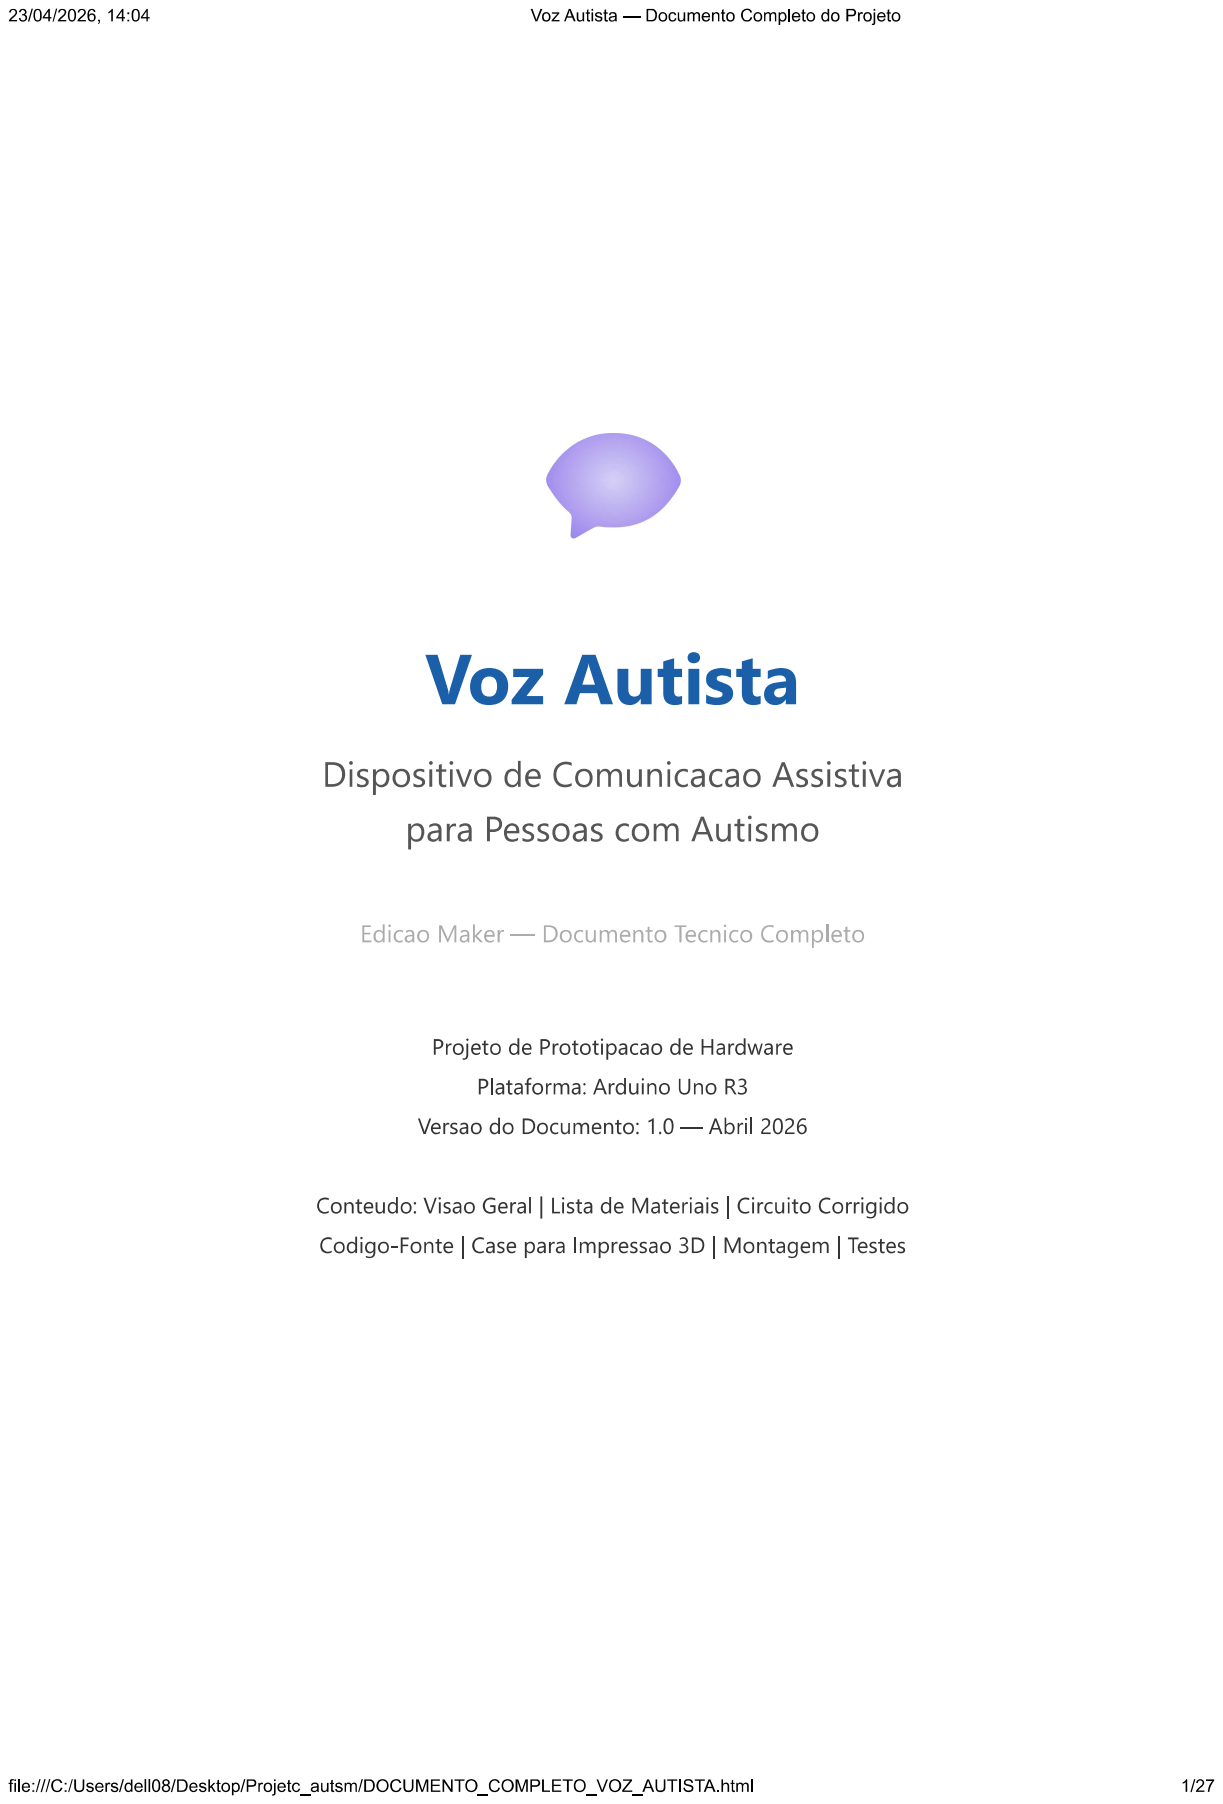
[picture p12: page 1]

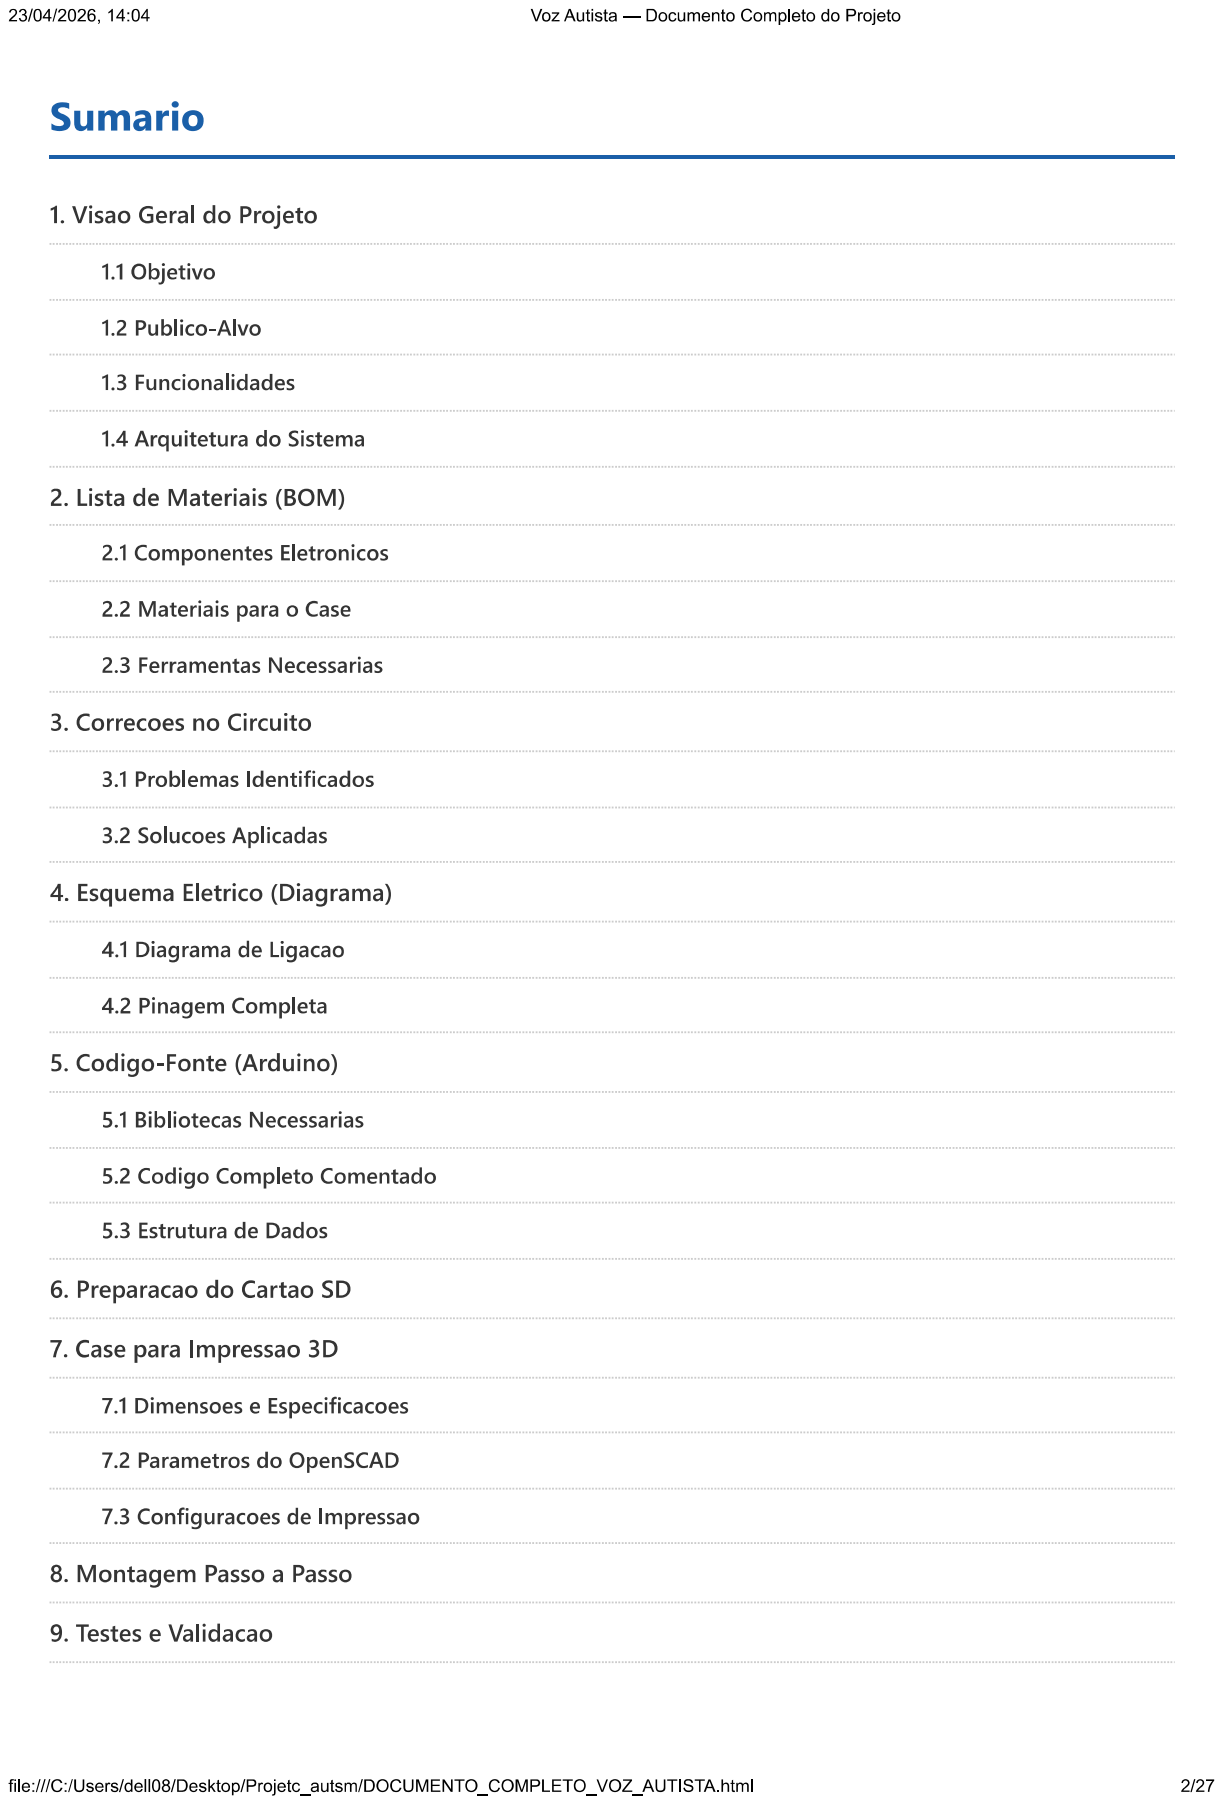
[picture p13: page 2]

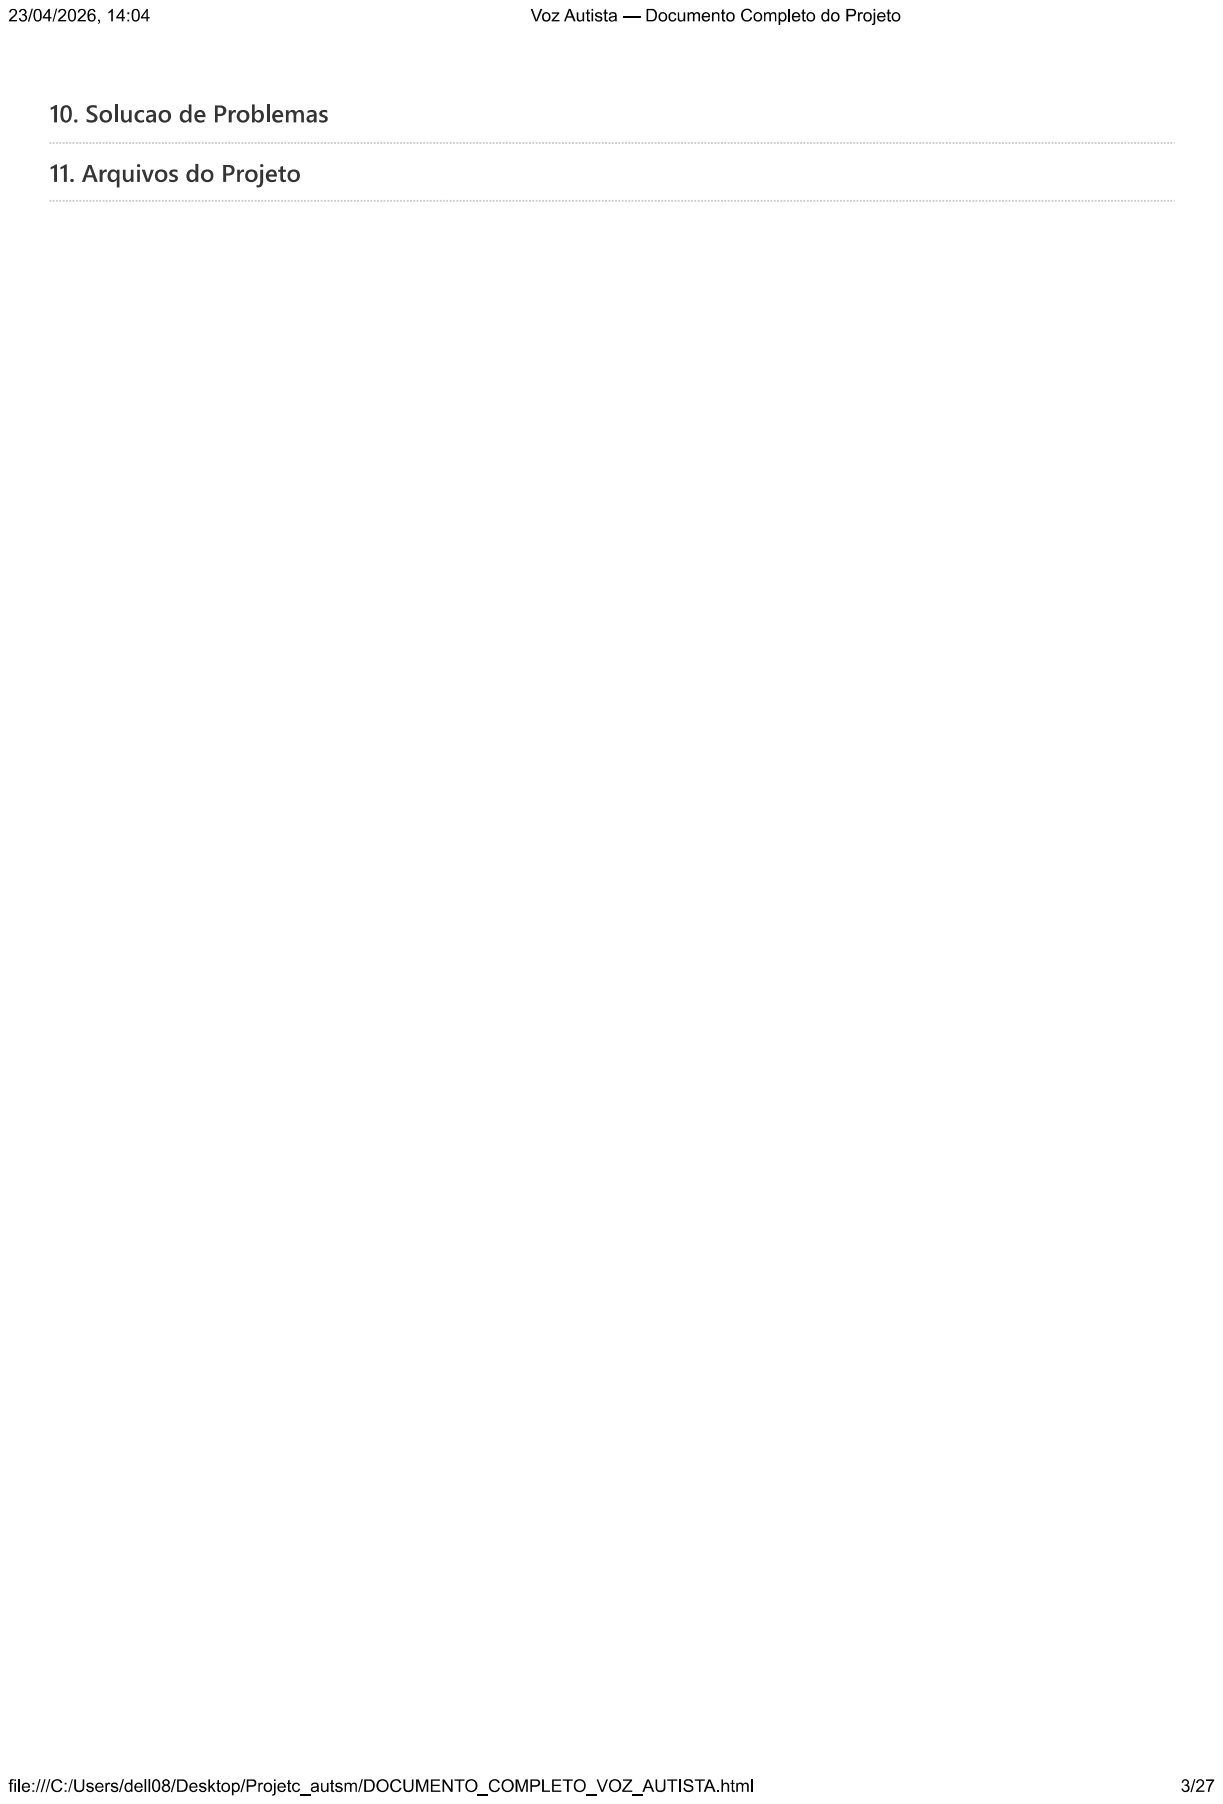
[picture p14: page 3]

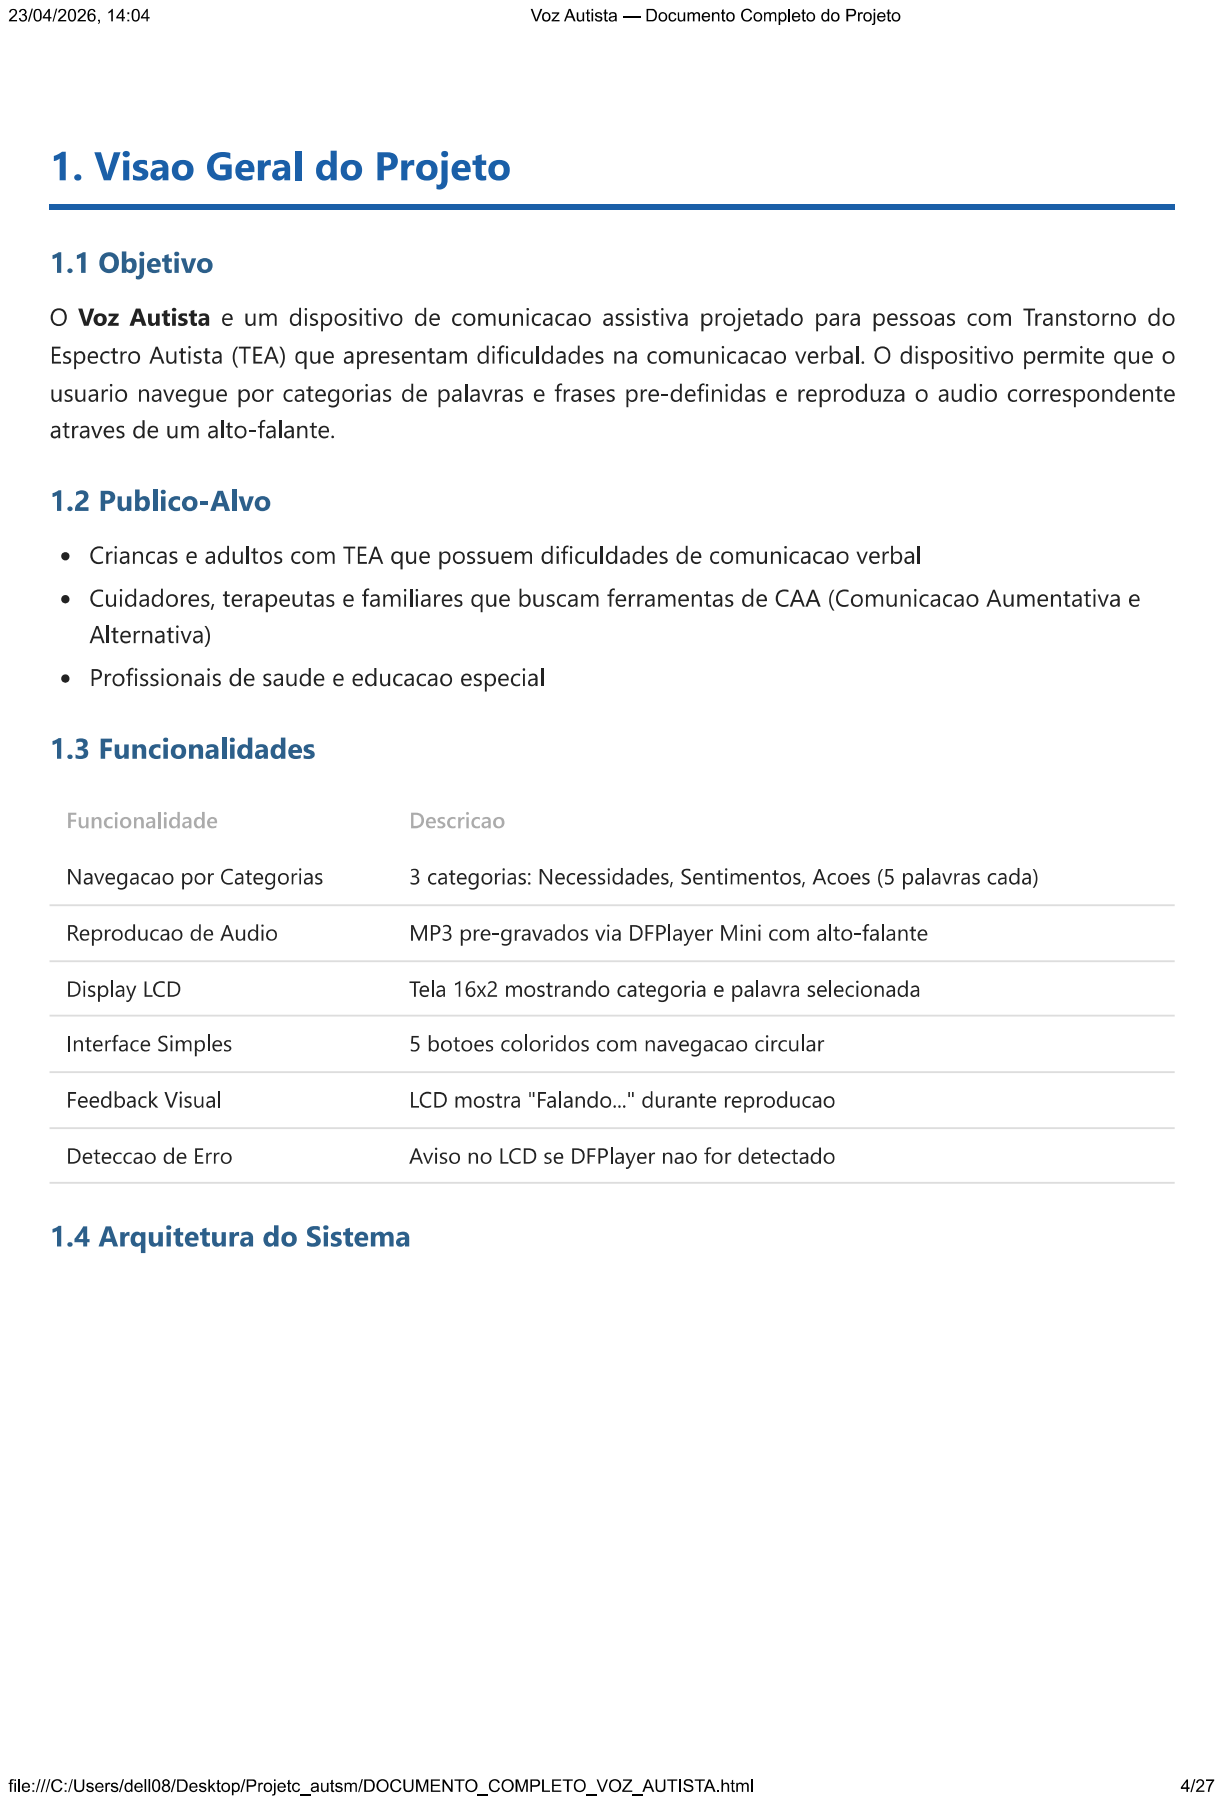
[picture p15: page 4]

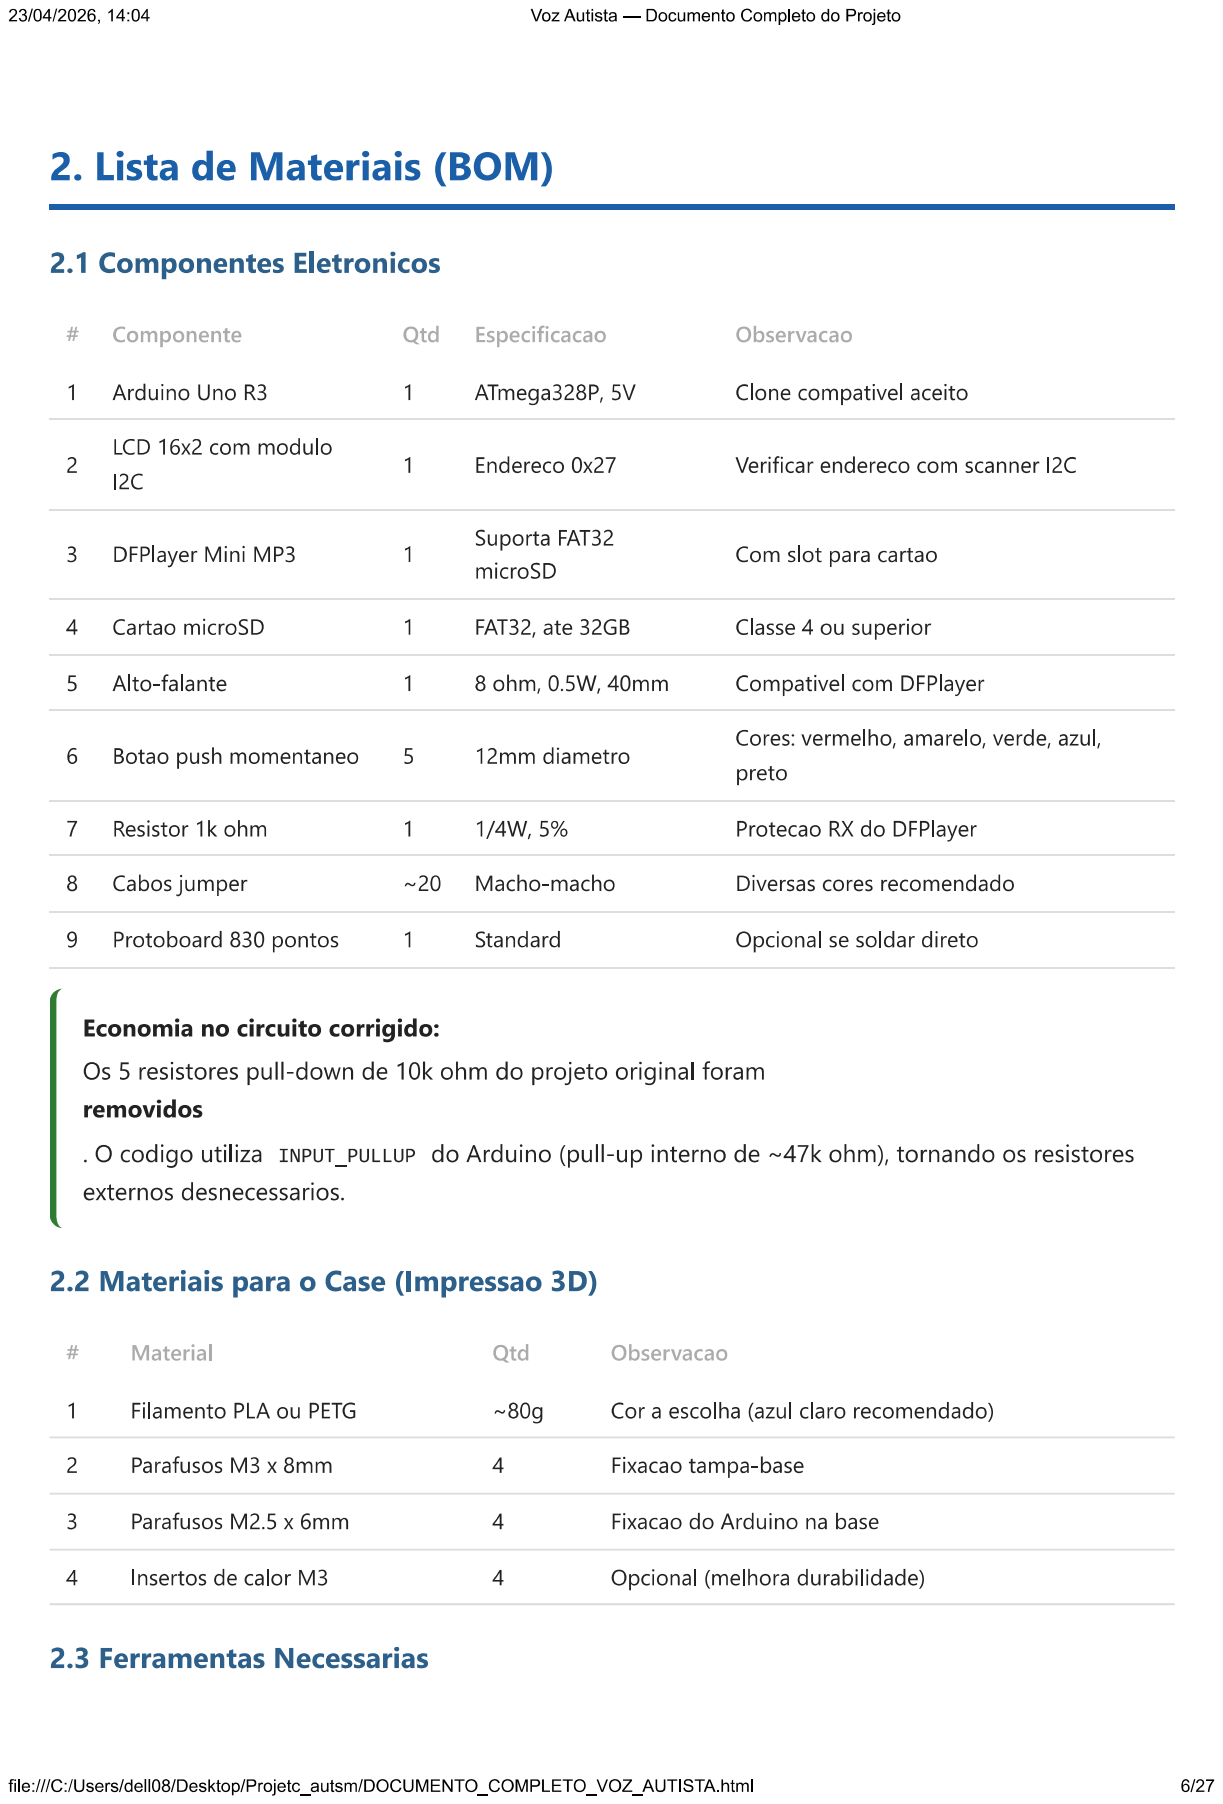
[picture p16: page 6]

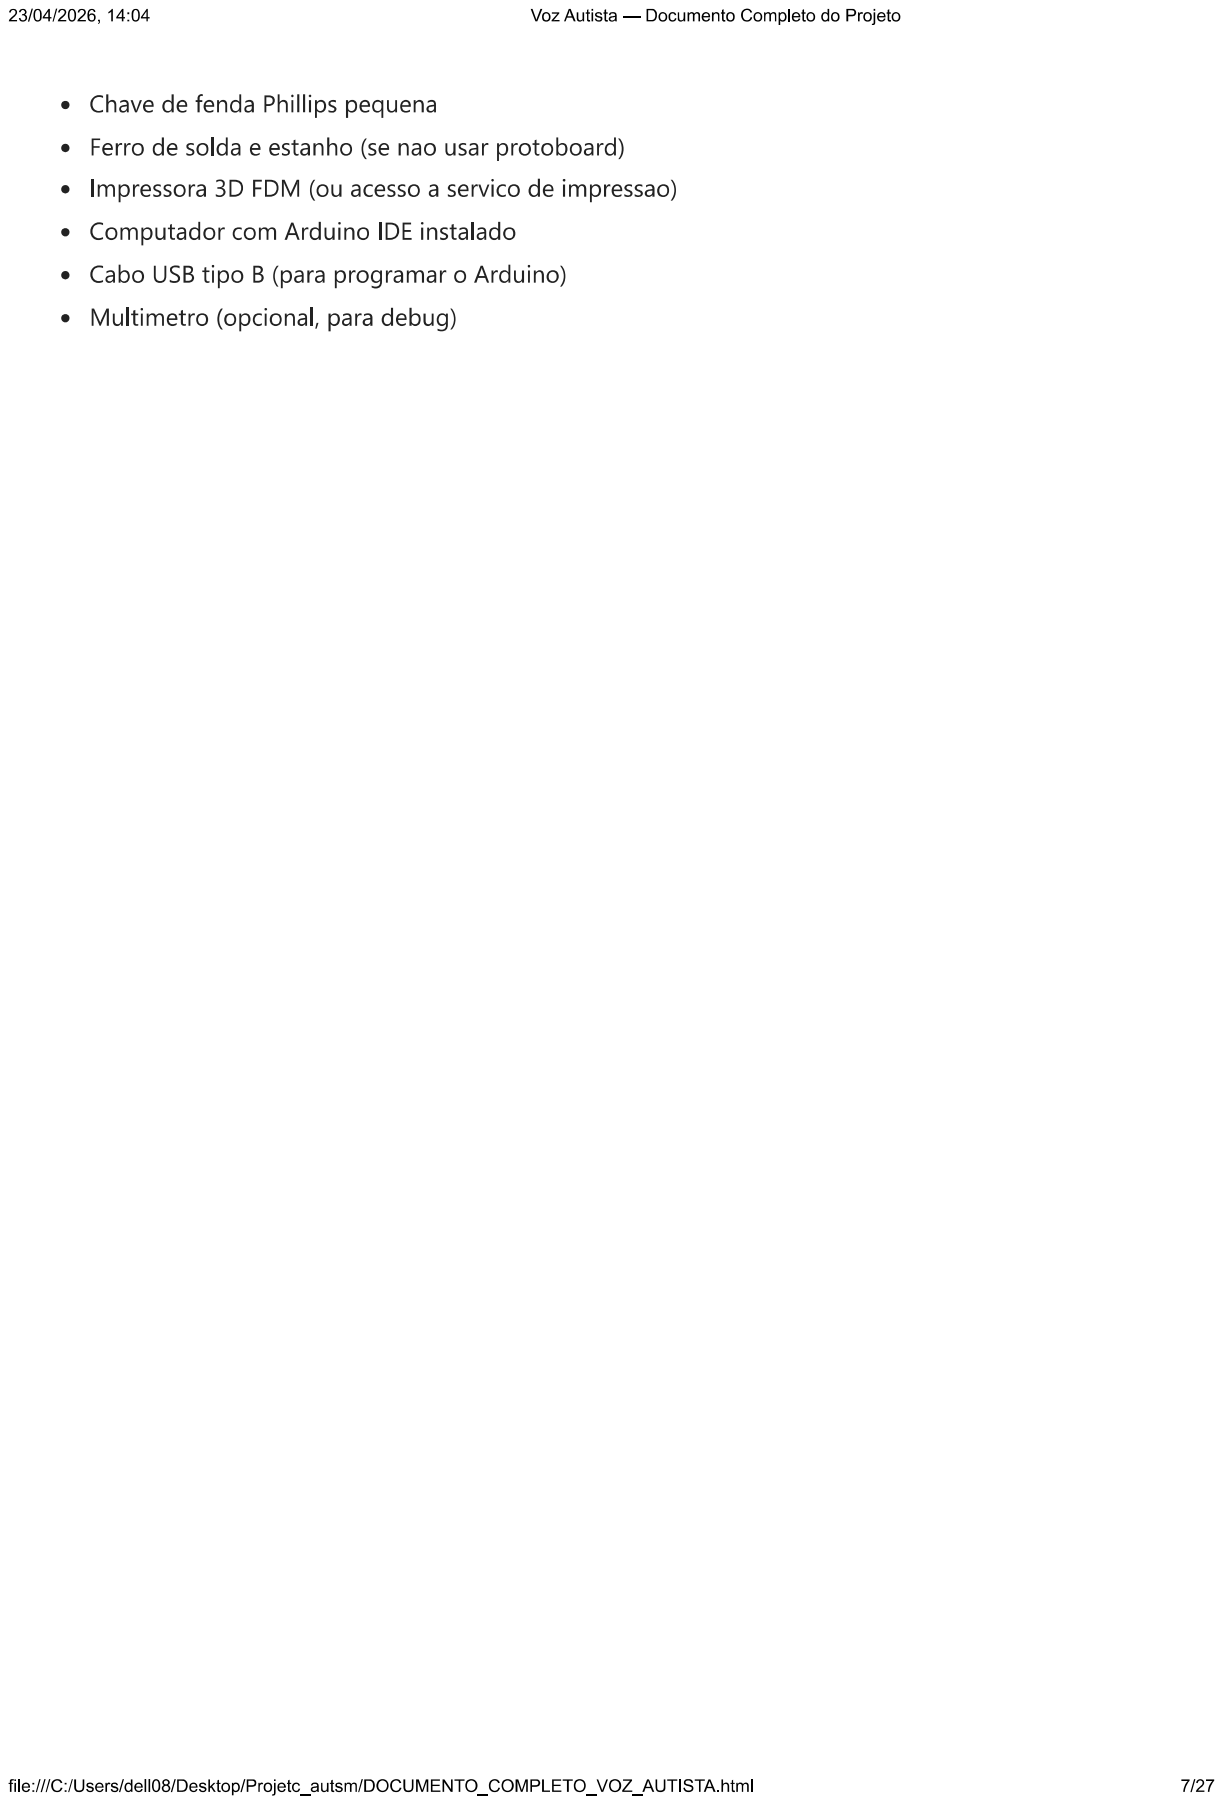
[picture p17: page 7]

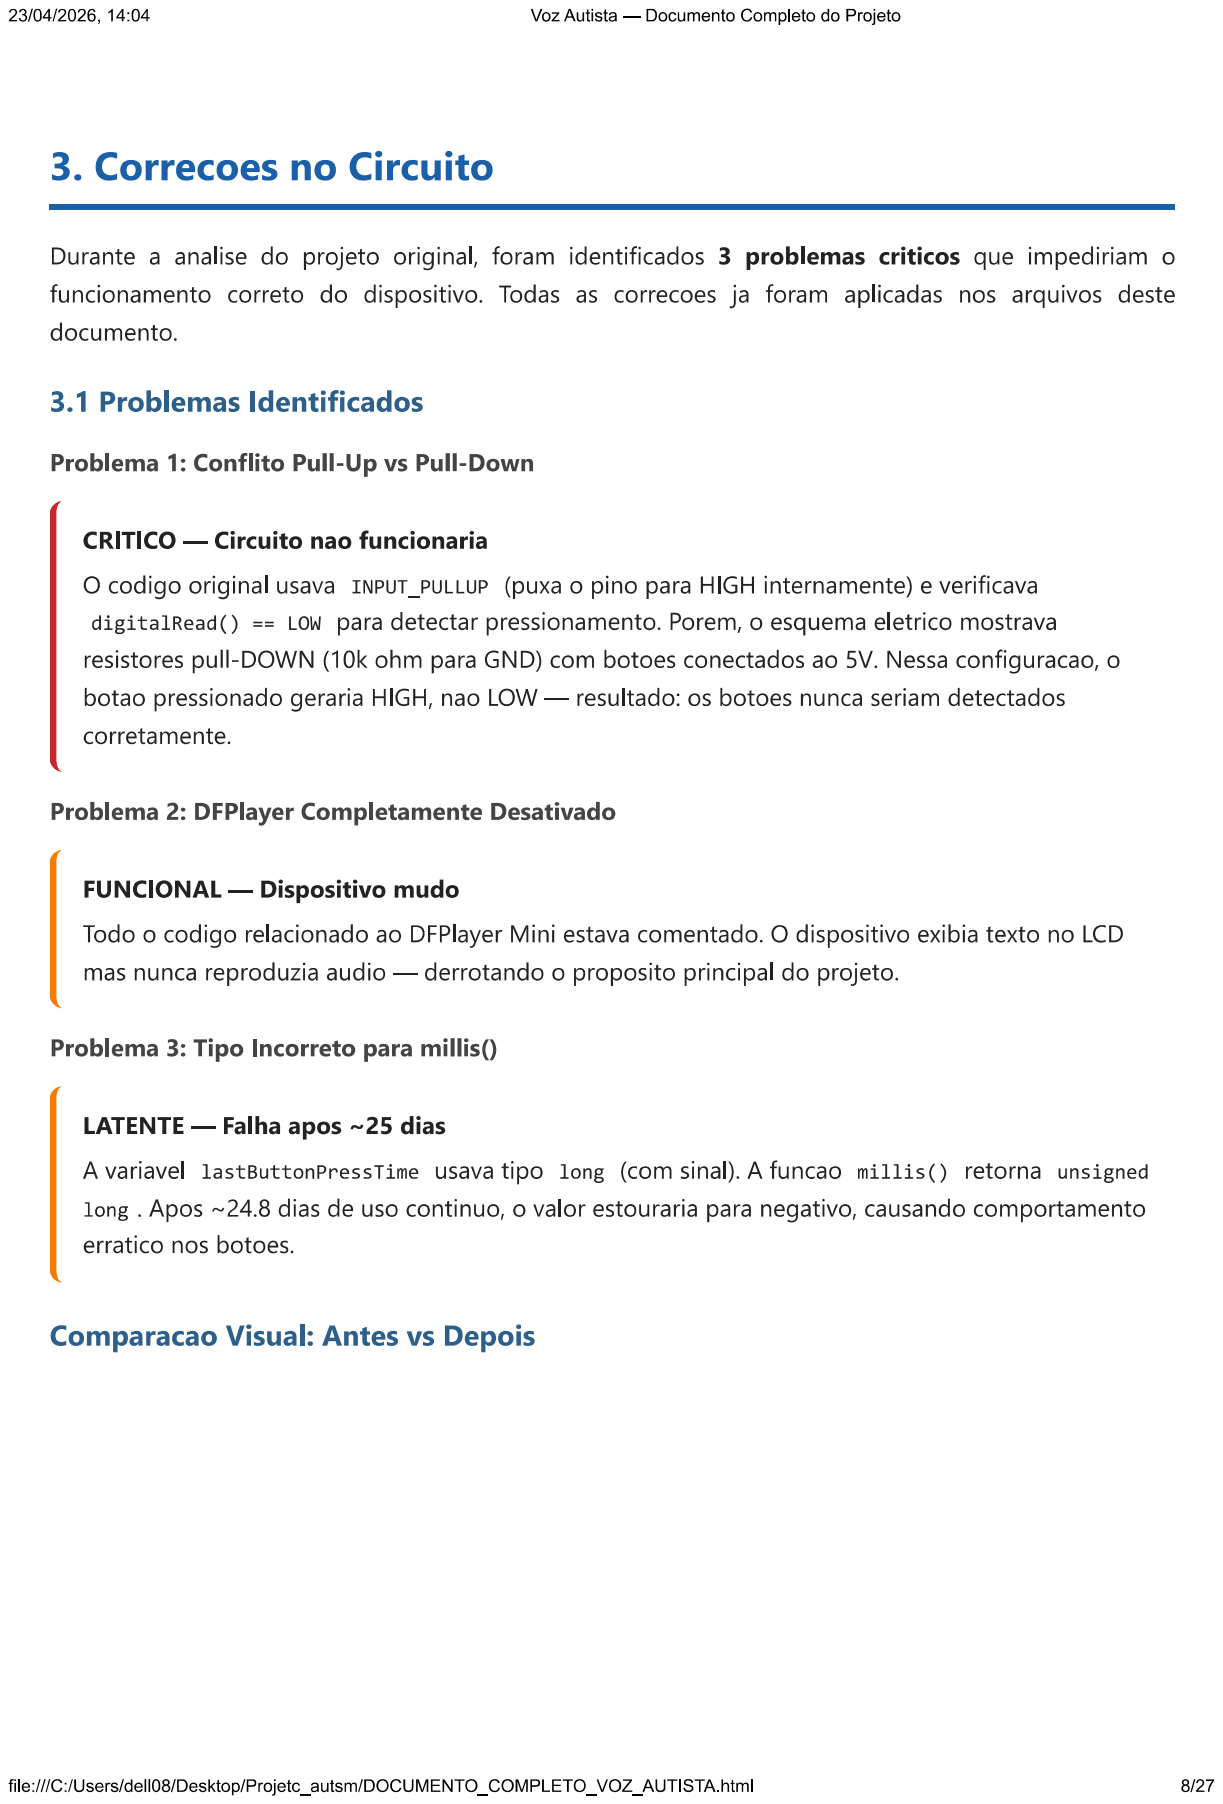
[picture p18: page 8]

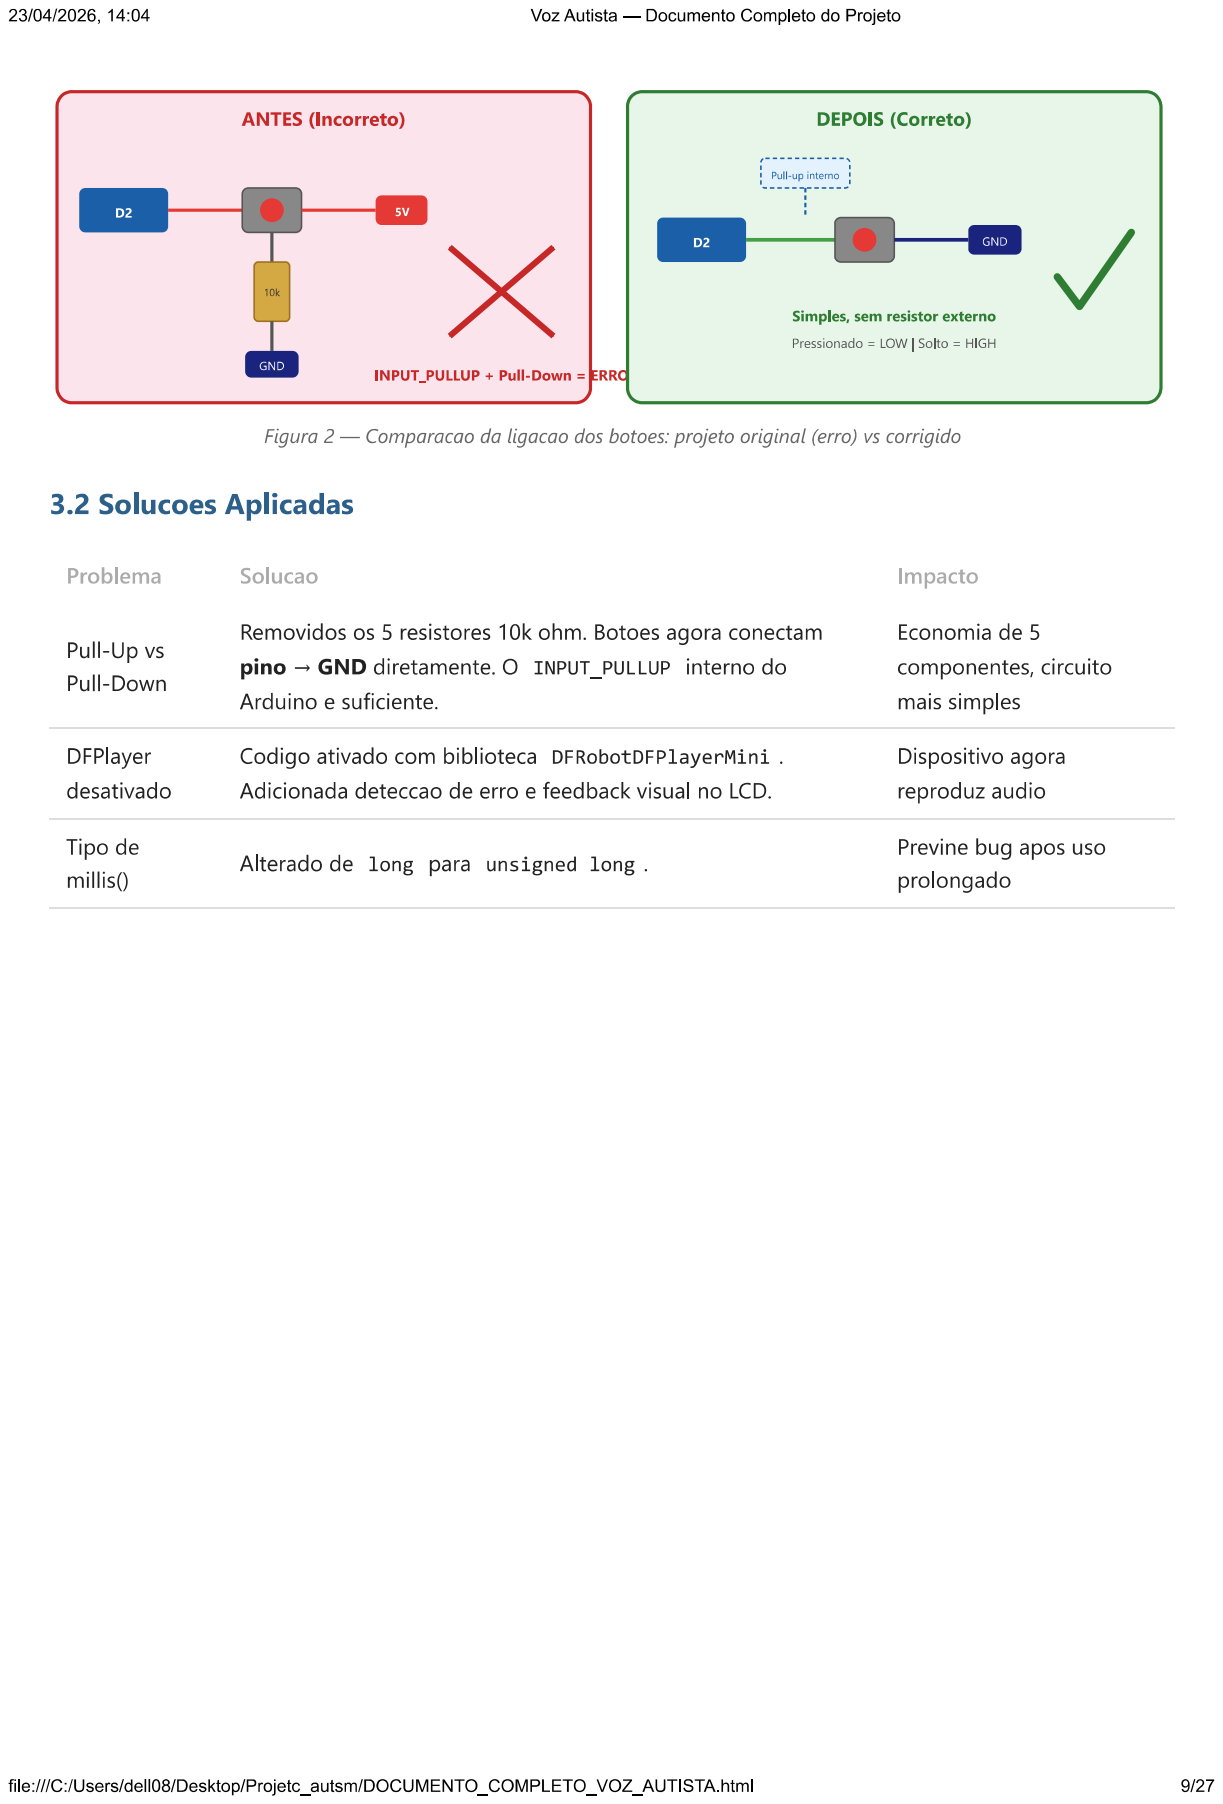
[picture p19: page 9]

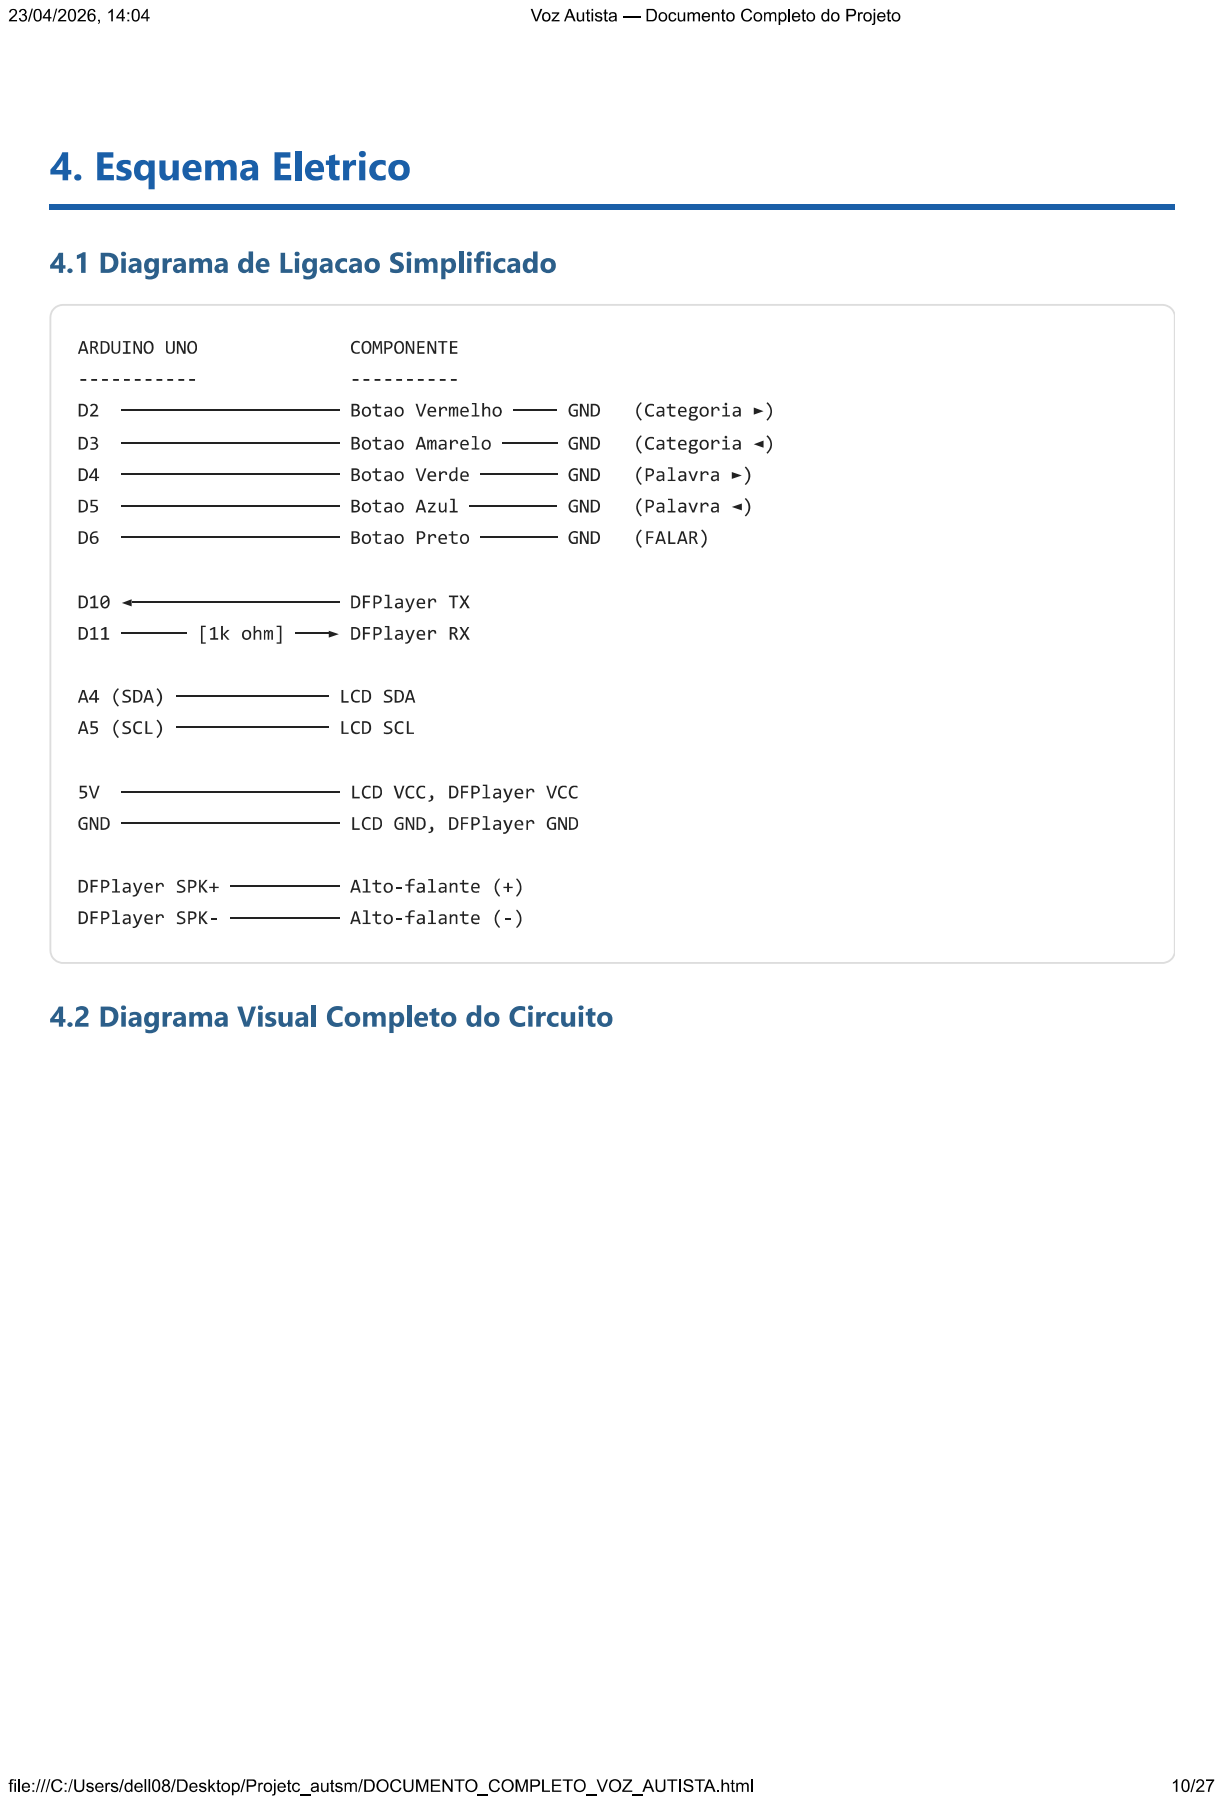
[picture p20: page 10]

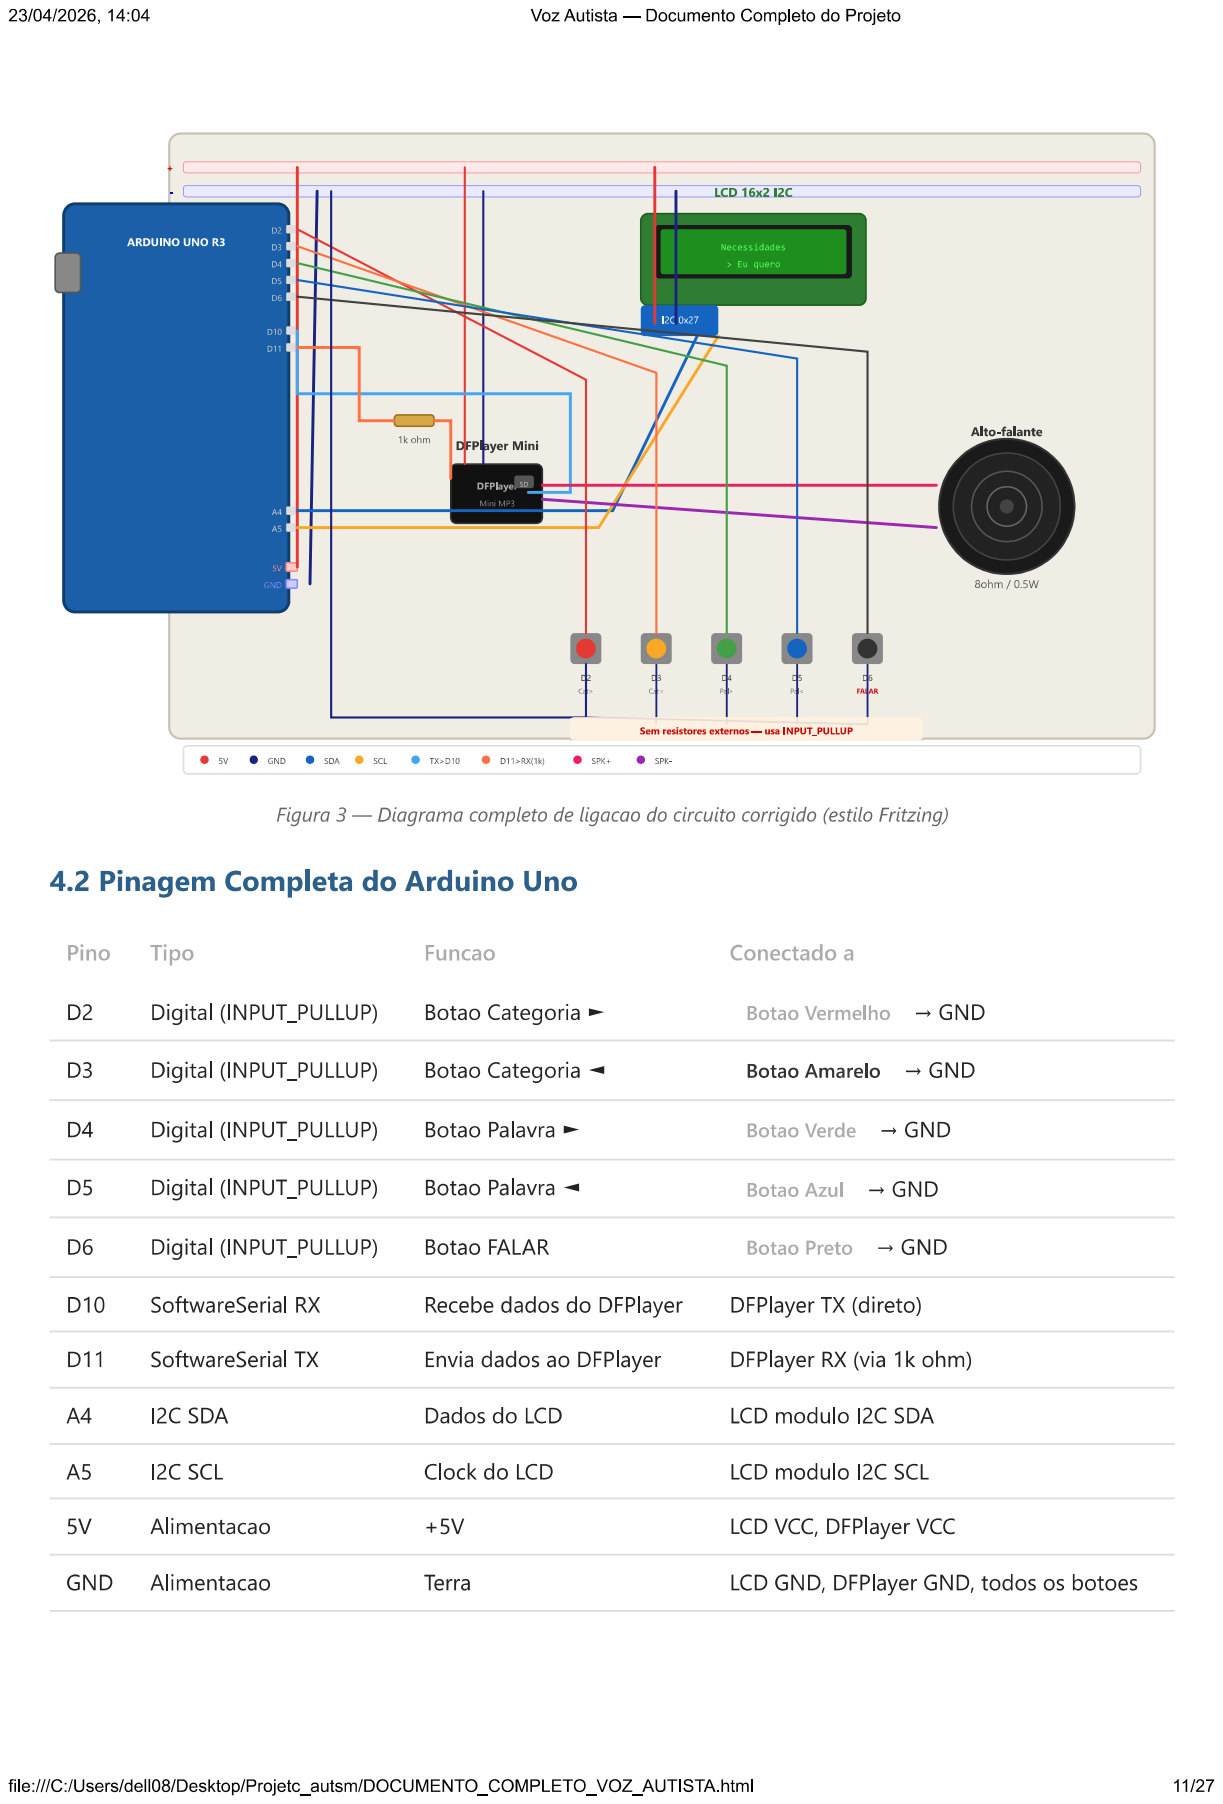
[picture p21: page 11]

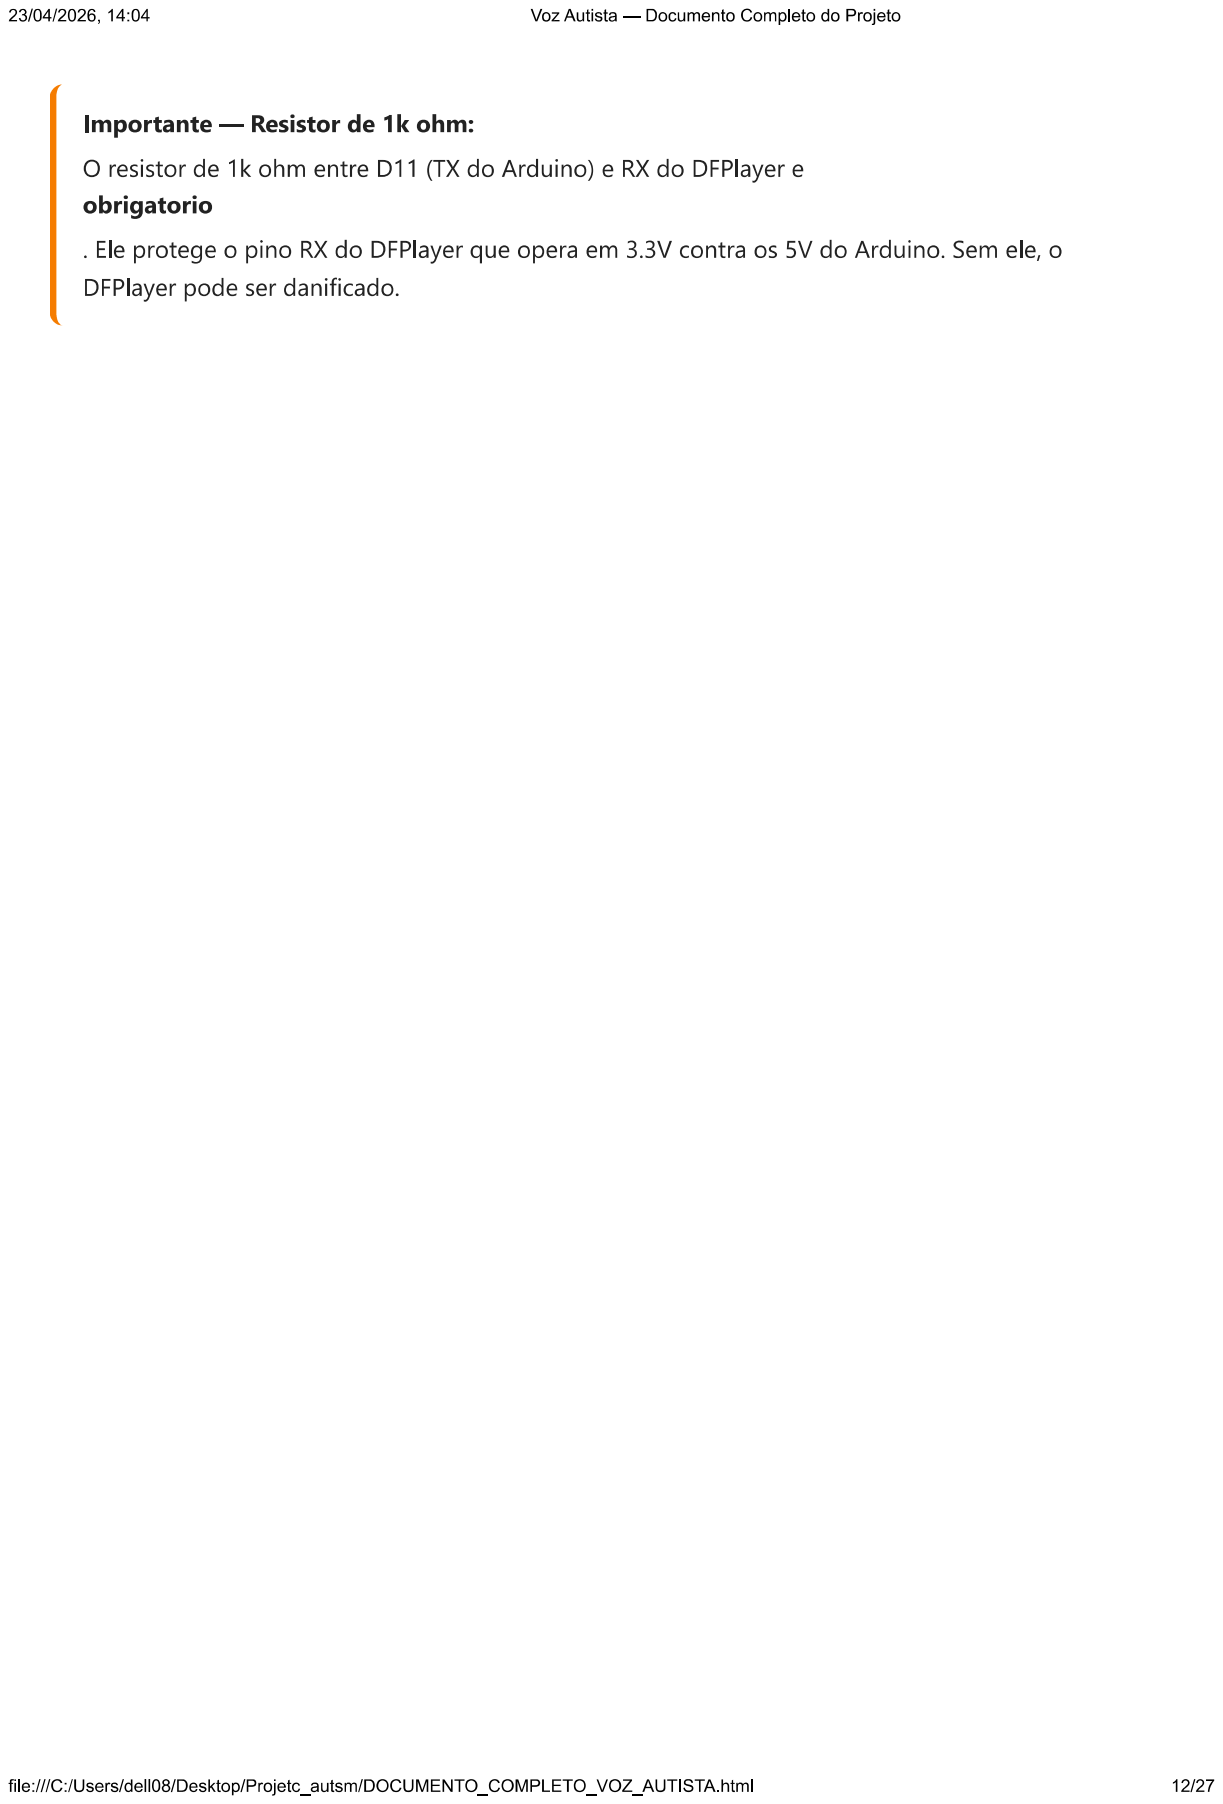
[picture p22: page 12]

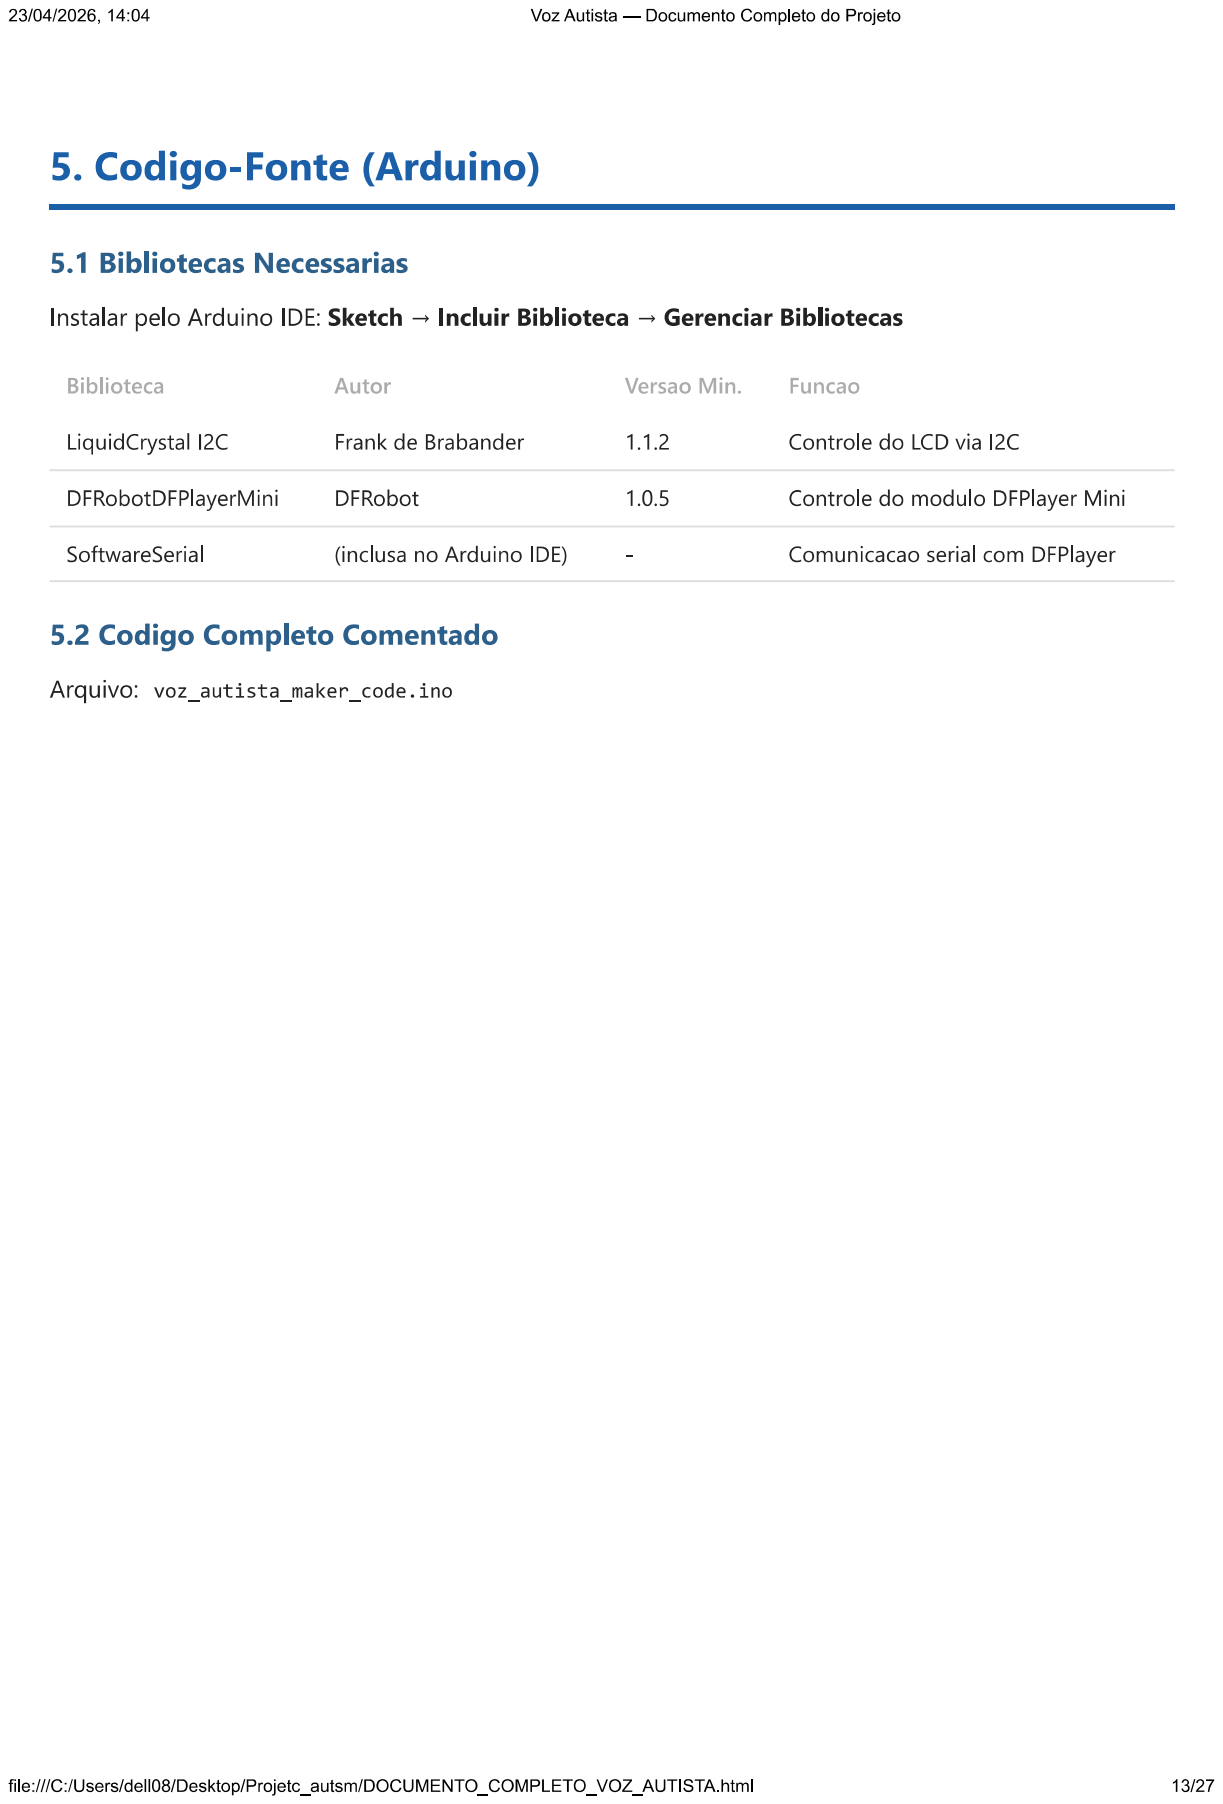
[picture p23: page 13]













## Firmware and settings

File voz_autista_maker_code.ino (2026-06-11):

// ============================================================
// Voz Autista v3.0 - Comunicador Assistivo
// Dispositivo de Comunicação para pessoas com autismo
// ============================================================
//
// MELHORIAS v3.0 (circuito):
//   - Divisor da bateria: 100kΩ+33kΩ + leitura com referência
//     interna 1.1V (corrige leitura ratiométrica e reduz dreno
//     da 18650 de ~210µA para ~32µA)
//   - DFPlayer RX protegido por divisor 1kΩ/2kΩ (lógica 3.3V)
//   - Capacitor 470µF + 100nF no VCC do DFPlayer (anti-reset)
//   - DFPlayer BUSY → D8: frases compostas esperam o áudio real
//     terminar (sem delay fixo)
//   - Alimentação: 18650 → TP4056 → chave → boost MT3608 → 5V
//     (rail 5V estável: LCD com contraste cheio, 16MHz em spec)
//
// MELHORIAS v2.0 (mantidas):
//   - 7 categorias com 35 palavras, volume por potenciômetro,
//     auto-detecção I2C, frase composta, vibração, sleep
//
// PINAGEM v3.0 (pinos idênticos à v2.0 + D8 novo):
//   D2  → Botão Vermelho (Cat+)     → GND
//   D3  → Botão Amarelo  (Cat-)     → GND
//   D4  → Botão Verde    (Pal+)     → GND
//   D5  → Botão Azul     (Pal-)     → GND
//   D6  → Botão Preto    (FALAR)    → GND
//   D7  → 1kΩ → Base 2N2222 → Motor vibração (flyback 1N4148)
//   D8  ← DFPlayer BUSY (LOW = tocando)                  [NOVO]
//   D10 ← DFPlayer TX
//   D11 → 1kΩ → DFPlayer RX → 2kΩ → GND  (divisor p/ 3.3V) [ATUALIZADO]
//   A0  ← Potenciômetro (volume)
//   A1  ← Divisor bateria 100kΩ/33kΩ + 100nF (ref 1.1V)   [ATUALIZADO]
//   A4  → LCD SDA (I2C)
//   A5  → LCD SCL (I2C)
//
// CARTÃO SD (pasta por categoria):
//   /01/001-005.mp3  Necessidades
//   /02/001-005.mp3  Sentimentos
//   /03/001-005.mp3  Ações
//   /04/001-005.mp3  Comidas
//   /05/001-005.mp3  Lugares
//   /06/001-005.mp3  Pessoas
//   /07/001-005.mp3  Saúde
// ============================================================

#include <Wire.h>
#include <LiquidCrystal_I2C.h>
#include <SoftwareSerial.h>
#include <DFRobotDFPlayerMini.h>

// =============================================================
// ██  SEÇÃO DE CONFIGURAÇÃO - EDITE AQUI PARA PERSONALIZAR  ██
// =============================================================
// Para adicionar/alterar categorias:
//   1. Edite o array 'categories[]' abaixo
//   2. Atualize NUM_CATEGORIES
//   3. Crie a pasta correspondente no SD card (/0X/)
//   4. Grave os MP3s como 001.mp3 a 005.mp3 em cada pasta
//
// Para alterar nomes dos botões, mude os labels no LCD.
// Para alterar a ordem dos botões, mude os pinos abaixo.
// =============================================================

// --- Estrutura de categoria ---
struct Category {
  const char* name;       // Nome exibido no LCD (máx 14 chars)
  const char* words[5];   // Até 5 palavras por categoria
  int numWords;           // Quantas palavras tem (1-5)
};

// --- CATEGORIAS E PALAVRAS ---
// Pasta do SD = índice da categoria + 1
// Arquivo do SD = índice da palavra + 1
// Ex: categories[2].words[3] → /03/004.mp3
Category categories[] = {
  // Categoria 0 → pasta /01/
  {"Necessidades", {"Eu quero", "Comer", "Beber", "Banheiro", "Dormir"}, 5},

  // Categoria 1 → pasta /02/
  {"Sentimentos",  {"Feliz", "Triste", "Bravo", "Calmo", "Medo"},        5},

  // Categoria 2 → pasta /03/
  {"Acoes",        {"Brincar", "Ajuda", "Sair", "Parar", "Ir"},          5},

  // Categoria 3 → pasta /04/
  {"Comidas",      {"Agua", "Suco", "Leite", "Pao", "Fruta"},            5},

  // Categoria 4 → pasta /05/
  {"Lugares",      {"Casa", "Escola", "Parque", "Medico", "Banho"},       5},

  // Categoria 5 → pasta /06/
  {"Pessoas",      {"Mamae", "Papai", "Vovo", "Professor", "Amigo"},      5},

  // Categoria 6 → pasta /07/
  {"Saude",        {"Doi", "Enjoo", "Frio", "Calor", "Cansado"},         5}
};

const int NUM_CATEGORIES = sizeof(categories) / sizeof(categories[0]);

// --- Pinos ---
const int btnCatUp     = 2;   // Vermelho - Categoria +
const int btnCatDown   = 3;   // Amarelo  - Categoria -
const int btnWordUp    = 4;   // Verde    - Palavra +
const int btnWordDown  = 5;   // Azul     - Palavra -
const int btnSpeak     = 6;   // Preto    - FALAR
const int pinVibrate   = 7;   // Motor de vibração
const int pinBusy      = 8;   // DFPlayer BUSY (LOW = tocando)   [v3.0]
const int pinVolume    = A0;  // Potenciômetro de volume
const int pinBattery   = A1;  // Divisor de tensão da bateria (100k/33k)

// --- Tempos (ms) ---
const unsigned long DEBOUNCE_DELAY   = 250;
const unsigned long LONG_PRESS_TIME  = 800;   // Tempo para press longo
const unsigned long SLEEP_TIMEOUT    = 120000; // 2 min para dormir
const unsigned long VOLUME_INTERVAL  = 500;    // Intervalo leitura volume
const unsigned long BATTERY_INTERVAL = 10000;  // Intervalo leitura bateria
const int VIBRATE_MS = 60;                     // Duração vibração (ms)
const int PHRASE_DELAY = 250;                  // Pausa entre palavras APÓS o áudio
                                               // terminar (v3.0: fim real via BUSY)

// --- Tamanho máximo da frase composta ---
const int MAX_PHRASE = 5;

// =============================================================
// ██  FIM DA SEÇÃO DE CONFIGURAÇÃO                           ██
// =============================================================

// --- DFPlayer ---
SoftwareSerial dfSerial(10, 11);
DFRobotDFPlayerMini dfPlayer;
bool dfPlayerReady = false;

// --- LCD (criado dinamicamente após detecção I2C) ---
LiquidCrystal_I2C* lcd = nullptr;

// --- Estado de navegação ---
int catIndex  = 0;
int wordIndex = 0;
int volume    = 20;

// --- Frase composta ---
struct PhraseWord {
  byte cat;
  byte word;
};
PhraseWord phraseBuffer[MAX_PHRASE];
int phraseCount = 0;

// --- Temporização ---
unsigned long lastButtonTime   = 0;
unsigned long lastVolumeTime   = 0;
unsigned long lastBatteryTime  = 0;
unsigned long lastActivityTime = 0;

// --- Botão FALAR (detecção long press) ---
bool speakBtnPrev        = false;
unsigned long speakPressStart = 0;

// --- Sleep ---
bool isSleeping = false;

// --- Bateria ---
int batteryPercent = 100;

// --- Caracteres customizados LCD ---
byte charArrow[8]   = {0x00,0x04,0x06,0x1F,0x1F,0x06,0x04,0x00};
byte charSpeaker[8] = {0x01,0x03,0x0F,0x0F,0x0F,0x03,0x01,0x00};
byte charBatFull[8] = {0x0E,0x1F,0x1F,0x1F,0x1F,0x1F,0x1F,0x1F};
byte charBatMid[8]  = {0x0E,0x11,0x11,0x1F,0x1F,0x1F,0x1F,0x1F};
byte charBatLow[8]  = {0x0E,0x11,0x11,0x11,0x11,0x11,0x1F,0x1F};
byte charPhrase[8]  = {0x00,0x0A,0x1F,0x1F,0x0E,0x04,0x00,0x00}; // coração = tem frase

// ===================== SETUP =====================
void setup() {
  Serial.begin(9600);
  dfSerial.begin(9600);

  // Pinos
  pinMode(btnCatUp,   INPUT_PULLUP);
  pinMode(btnCatDown,  INPUT_PULLUP);
  pinMode(btnWordUp,   INPUT_PULLUP);
  pinMode(btnWordDown, INPUT_PULLUP);
  pinMode(btnSpeak,    INPUT_PULLUP);
  pinMode(pinVibrate,  OUTPUT);
  digitalWrite(pinVibrate, LOW);
  // BUSY do DFPlayer: pull-up interno garante leitura HIGH ("parado")
  // se o fio estiver desconectado - o fallback por timeout assume o resto
  pinMode(pinBusy, INPUT_PULLUP);

  // Detecta endereço I2C do LCD
  byte lcdAddr = detectI2C();
  lcd = new LiquidCrystal_I2C(lcdAddr, 16, 2);
  lcd->init();
  lcd->backlight();

  // Caracteres customizados
  lcd->createChar(0, charArrow);
  lcd->createChar(1, charSpeaker);
  lcd->createChar(2, charBatFull);
  lcd->createChar(3, charBatMid);
  lcd->createChar(4, charBatLow);
  lcd->createChar(5, charPhrase);

  // Splash
  lcd->setCursor(2, 0);
  lcd->print(F("Voz Autista"));
  lcd->setCursor(2, 1);
  lcd->print(F("v3.0  Maker"));
  Serial.print(F("LCD I2C addr: 0x"));
  Serial.println(lcdAddr, HEX);

  // Volume inicial do potenciômetro
  volume = map(analogRead(pinVolume), 0, 1023, 0, 30);

  // DFPlayer
  delay(1000);
  if (dfPlayer.begin(dfSerial)) {
    dfPlayerReady = true;
    dfPlayer.outputDevice(DFPLAYER_DEVICE_SD);
    dfPlayer.volume(volume);
    Serial.println(F("DFPlayer OK"));
  } else {
    Serial.println(F("DFPlayer ERRO"));
    lcd->clear();
    lcd->print(F("ERRO: DFPlayer"));
    lcd->setCursor(0, 1);
    lcd->print(F("Cheque SD/fios"));
    delay(2500);
  }

  // Bateria inicial
  batteryPercent = readBattery();

  // Info serial
  Serial.print(F("Categorias: "));
  Serial.println(NUM_CATEGORIES);
  Serial.print(F("Volume: "));
  Serial.println(volume);

  lastActivityTime = millis();
  delay(800);
  lcd->clear();
  displaySelection();
}

// ===================== LOOP =====================
void loop() {
  unsigned long now = millis();

  // --- Sleep check ---
  if (!isSleeping && (now - lastActivityTime > SLEEP_TIMEOUT)) {
    enterSleep();
    return;
  }
  if (isSleeping) {
    // Qualquer botão acorda
    if (anyButtonPressed()) {
      wakeUp();
    }
    delay(50);
    return;
  }

  // --- Volume (potenciômetro) ---
  if (now - lastVolumeTime > VOLUME_INTERVAL) {
    updateVolume();
    lastVolumeTime = now;
  }

  // --- Bateria ---
  if (now - lastBatteryTime > BATTERY_INTERVAL) {
    batteryPercent = readBattery();
    displayBattery();
    lastBatteryTime = now;
  }

  // --- Debounce ---
  if (now - lastButtonTime < DEBOUNCE_DELAY) {
    // Botão FALAR precisa tracking contínuo mesmo durante debounce
    trackSpeakButton(now);
    return;
  }

  // --- Combos especiais (verificar ANTES dos individuais) ---
  bool catUpDown   = (digitalRead(btnCatUp) == LOW && digitalRead(btnCatDown) == LOW);
  bool wordUpDown  = (digitalRead(btnWordUp) == LOW && digitalRead(btnWordDown) == LOW);

  if (catUpDown && phraseCount > 0) {
    // Cat+ e Cat- juntos = falar frase completa
    speakPhrase();
    lastButtonTime = now;
    lastActivityTime = now;
    return;
  }
  if (wordUpDown && phraseCount > 0) {
    // Pal+ e Pal- juntos = limpar frase
    clearPhrase();
    lastButtonTime = now;
    lastActivityTime = now;
    return;
  }

  // --- Navegação de categorias ---
  if (digitalRead(btnCatUp) == LOW) {
    catIndex = (catIndex + 1) % NUM_CATEGORIES;
    wordIndex = 0;
    vibrate();
    displaySelection();
    lastButtonTime = now;
    lastActivityTime = now;
  }
  else if (digitalRead(btnCatDown) == LOW) {
    catIndex = (catIndex - 1 + NUM_CATEGORIES) % NUM_CATEGORIES;
    wordIndex = 0;
    vibrate();
    displaySelection();
    lastButtonTime = now;
    lastActivityTime = now;
  }
  // --- Navegação de palavras ---
  else if (digitalRead(btnWordUp) == LOW) {
    int n = categories[catIndex].numWords;
    wordIndex = (wordIndex + 1) % n;
    vibrate();
    displaySelection();
    lastButtonTime = now;
    lastActivityTime = now;
  }
  else if (digitalRead(btnWordDown) == LOW) {
    int n = categories[catIndex].numWords;
    wordIndex = (wordIndex - 1 + n) % n;
    vibrate();
    displaySelection();
    lastButtonTime = now;
    lastActivityTime = now;
  }

  // --- Botão FALAR (long press detection) ---
  trackSpeakButton(now);
}

// ===================== BOTÃO FALAR =====================
void trackSpeakButton(unsigned long now) {
  bool pressed = (digitalRead(btnSpeak) == LOW);

  if (pressed && !speakBtnPrev) {
    // Acabou de pressionar
    speakPressStart = now;
  }
  else if (!pressed && speakBtnPrev) {
    // Acabou de soltar
    unsigned long holdTime = now - speakPressStart;
    lastActivityTime = now;
    lastButtonTime = now;

    if (holdTime >= LONG_PRESS_TIME) {
      // Long press → adiciona à frase
      addToPhrase();
    } else {
      // Short press → fala imediatamente
      speakCurrentWord();
    }
  }
  speakBtnPrev = pressed;
}

// ===================== DISPLAY =====================
void displaySelection() {
  lcd->clear();

  // Linha 1: categoria + bateria
  lcd->setCursor(0, 0);
  lcd->print(categories[catIndex].name);
  displayBattery();

  // Linha 2: seta + palavra + indicador frase
  lcd->setCursor(0, 1);
  lcd->write(byte(0)); // seta
  lcd->print(' ');
  lcd->print(categories[catIndex].words[wordIndex]);

  // Indicador de frase (canto inferior direito)
  if (phraseCount > 0) {
    lcd->setCursor(14, 1);
    lcd->write(byte(5)); // coração
    lcd->print(phraseCount);
  }
}

void displayBattery() {
  lcd->setCursor(15, 0);
  if (batteryPercent > 60)
    lcd->write(byte(2));      // cheio
  else if (batteryPercent > 20)
    lcd->write(byte(3));      // meio
  else
    lcd->write(byte(4));      // baixo
}

// ===================== FALAR =====================
void speakCurrentWord() {
  const char* word = categories[catIndex].words[wordIndex];
  int folder = catIndex + 1;
  int file   = wordIndex + 1;

  vibrate();

  // Feedback visual
  lcd->clear();
  lcd->setCursor(0, 0);
  lcd->write(byte(1));
  lcd->print(F(" Falando..."));
  lcd->setCursor(0, 1);
  lcd->print(word);

  Serial.print(F("Falar: "));
  Serial.print(word);
  Serial.print(F(" [/0"));
  Serial.print(folder);
  Serial.print(F("/00"));
  Serial.print(file);
  Serial.println(F(".mp3]"));

  if (dfPlayerReady) {
    dfPlayer.playFolder(folder, file);
  }

  delay(600);
  displaySelection();
}

// ===================== FRASE COMPOSTA =====================
void addToPhrase() {
  if (phraseCount >= MAX_PHRASE) {
    // Buffer cheio - feedback
    lcd->clear();
    lcd->print(F("Frase cheia!"));
    lcd->setCursor(0, 1);
    lcd->print(F("Max "));
    lcd->print(MAX_PHRASE);
    lcd->print(F(" palavras"));
    vibrate();
    delay(50);
    vibrate();
    delay(1000);
    displaySelection();
    return;
  }

  phraseBuffer[phraseCount].cat  = catIndex;
  phraseBuffer[phraseCount].word = wordIndex;
  phraseCount++;

  vibrate();

  // Feedback visual
  lcd->clear();
  lcd->setCursor(0, 0);
  lcd->print(F("+ "));
  lcd->print(categories[catIndex].words[wordIndex]);
  lcd->setCursor(0, 1);
  lcd->print(F("Frase: "));
  lcd->print(phraseCount);
  lcd->print(F("/"));
  lcd->print(MAX_PHRASE);

  Serial.print(F("Frase +: "));
  Serial.print(categories[catIndex].words[wordIndex]);
  Serial.print(F(" ("));
  Serial.print(phraseCount);
  Serial.println(F(" palavras)"));

  delay(800);
  displaySelection();
}

void speakPhrase() {
  if (phraseCount == 0) return;

  vibrate();

  lcd->clear();
  lcd->setCursor(0, 0);
  lcd->write(byte(1));
  lcd->print(F(" Frase ("));
  lcd->print(phraseCount);
  lcd->print(F(")..."));

  Serial.print(F("Frase completa: "));

  for (int i = 0; i < phraseCount; i++) {
    int c = phraseBuffer[i].cat;
    int w = phraseBuffer[i].word;
    const char* word = categories[c].words[w];

    lcd->setCursor(0, 1);
    lcd->print(F("                ")); // limpa linha
    lcd->setCursor(0, 1);
    lcd->print(word);

    Serial.print(word);
    if (i < phraseCount - 1) Serial.print(F(" + "));

    if (dfPlayerReady) {
      dfPlayer.playFolder(c + 1, w + 1);
    }

    if (i < phraseCount - 1) {
      // v3.0: espera o MP3 terminar de verdade (BUSY em D8) em vez
      // de pausa fixa - a frase soa natural com áudios de qualquer duração
      waitAudioEnd(8000);
      delay(PHRASE_DELAY);
    }
  }

  Serial.println();

  delay(800);

  // Limpa frase após falar
  phraseCount = 0;
  displaySelection();
}

void clearPhrase() {
  phraseCount = 0;
  vibrate();
  lcd->clear();
  lcd->print(F("Frase limpa"));
  Serial.println(F("Frase limpa"));
  delay(800);
  displaySelection();
}

// ===================== VOLUME =====================
void updateVolume() {
  int raw = analogRead(pinVolume);
  int newVol = map(raw, 0, 1023, 0, 30);
  if (abs(newVol - volume) > 1) {
    volume = newVol;
    if (dfPlayerReady) {
      dfPlayer.volume(volume);
    }
  }
}

// ===================== BATERIA =====================
int readBattery() {
  // v3.0: divisor 100kΩ (Vbat→A1) + 33kΩ (A1→GND) + 100nF em A1,
  // lido contra a REFERÊNCIA INTERNA de 1.1V do ATmega328.
  //
  // Por que não medir contra VCC (DEFAULT)? Porque com bateria o
  // próprio VCC varia com a carga - a leitura ratiométrica ficaria
  // constante e o medidor nunca mudaria. A ref. interna é absoluta.
  //
  // 18650: 4.2V (cheia) → 4.2×33/133 = 1.042V → ADC ~969
  //        3.0V (vazia) → 3.0×33/133 = 0.744V → ADC ~692
  // O 100nF compensa a impedância alta do divisor para o ADC.
  analogReference(INTERNAL);     // 1.1V
  analogRead(pinBattery);        // descarta 1ª leitura (ref estabilizando)
  delay(2);
  int raw = analogRead(pinBattery);
  analogReference(DEFAULT);      // volta p/ VCC (potenciômetro de volume)
  analogRead(pinVolume);         // descarta leitura de transição
  int pct = map(raw, 692, 969, 0, 100);
  return constrain(pct, 0, 100);
}

// ===================== ÁUDIO - ESPERA FIM (v3.0) =====================
// O pino BUSY do DFPlayer fica LOW enquanto um MP3 toca.
// Espera o áudio terminar, com timeout de segurança (fio solto, etc).
void waitAudioEnd(unsigned long timeoutMs) {
  if (!dfPlayerReady) { delay(800); return; }
  unsigned long t0 = millis();
  delay(200);  // o DFPlayer demora ~150ms para baixar o BUSY
  while (digitalRead(pinBusy) == LOW && (millis() - t0) < timeoutMs) {
    delay(10);
  }
}

// ===================== VIBRAÇÃO =====================
void vibrate() {
  digitalWrite(pinVibrate, HIGH);
  delay(VIBRATE_MS);
  digitalWrite(pinVibrate, LOW);
}

// ===================== SLEEP =====================
void enterSleep() {
  isSleeping = true;
  lcd->noBacklight();
  Serial.println(F("Sleep"));
}

void wakeUp() {
  isSleeping = false;
  lcd->backlight();
  lastActivityTime = millis();
  lastButtonTime = millis(); // evita ação do botão que acordou
  displaySelection();
  Serial.println(F("Wake"));
  delay(200);
}

bool anyButtonPressed() {
  return (digitalRead(btnCatUp) == LOW ||
          digitalRead(btnCatDown) == LOW ||
          digitalRead(btnWordUp) == LOW ||
          digitalRead(btnWordDown) == LOW ||
          digitalRead(btnSpeak) == LOW);
}

// ===================== I2C AUTO DETECT =====================
byte detectI2C() {
  Wire.begin();
  byte addrs[] = {0x27, 0x3F, 0x20, 0x38};
  for (byte i = 0; i < 4; i++) {
    Wire.beginTransmission(addrs[i]);
    if (Wire.endTransmission() == 0) {
      Serial.print(F("I2C encontrado: 0x"));
      Serial.println(addrs[i], HEX);
      return addrs[i];
    }
  }
  Serial.println(F("I2C nao detectado, usando 0x27"));
  return 0x27;
}

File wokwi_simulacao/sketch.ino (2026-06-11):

// ============================================================
// Voz Autista v3.0 - Simulacao Wokwi
// Comunicador Assistivo para pessoas com autismo
// ============================================================
//
// SIMULACAO WOKWI v3.0 - Equivalencias com o hardware real:
//   DFPlayer Mini  -> Buzzer no pino D9 (Wokwi nao tem DFPlayer)
//   Motor vibracao -> Circuito REAL do driver: D7 -> 1k -> 2N2222,
//                     com LED como carga indicadora (Wokwi nao tem
//                     motor DC; o 1N4148 fica so no hardware real)
//   Volume pot     -> Potenciometro em A0 (igual ao real)
//   Bateria        -> Potenciometro como "fonte variavel" alimentando
//                     o DIVISOR REAL 100k/33k que chega em A1
//   LCD I2C        -> LCD 16x2 I2C (0x27)
//
// PINAGEM v3.0 (identica ao hardware real; D9 so existe na simulacao):
//   D2  -> Botao Vermelho (Cat+)   -> GND
//   D3  -> Botao Amarelo  (Cat-)   -> GND
//   D4  -> Botao Verde    (Pal+)   -> GND
//   D5  -> Botao Azul     (Pal-)   -> GND
//   D6  -> Botao Preto    (FALAR)  -> GND
//   D7  -> 1k -> base 2N2222 (LED indica "vibracao")
//   D8  <- (BUSY do DFPlayer no real; nao usado na simulacao)
//   D9  -> Buzzer (simula DFPlayer; no real: D10/D11 SoftwareSerial)
//   A0  <- Potenciometro (volume)
//   A1  <- Divisor 100k/33k alimentado pelo pot "bateria" (ref 1.1V)
//   A4  -> LCD SDA (I2C)
//   A5  -> LCD SCL (I2C)
//
// FUNCIONALIDADES (iguais a v2.0):
//   - 7 categorias, 35 palavras
//   - Volume via potenciometro
//   - Bateria simulada com icone
//   - Frase composta (empilhar ate 5 palavras)
//   - Feedback tatil (LED simula vibracao)
//   - Sleep apos 2 min inatividade
//   - Caracteres customizados no LCD
// ============================================================

#include <Wire.h>
#include <LiquidCrystal_I2C.h>

// --- LCD I2C (sempre 0x27 no Wokwi) ---
LiquidCrystal_I2C lcd(0x27, 16, 2);

// --- Pinos ---
const int btnCatUp    = 2;   // Vermelho - Categoria +
const int btnCatDown  = 3;   // Amarelo  - Categoria -
const int btnWordUp   = 4;   // Verde    - Palavra +
const int btnWordDown = 5;   // Azul     - Palavra -
const int btnSpeak    = 6;   // Preto    - FALAR
const int pinVibrate  = 7;   // LED verde (simula motor vibracao)
const int buzzerPin   = 9;   // Buzzer (simula DFPlayer)
const int pinVolume   = A0;  // Potenciometro volume
const int pinBattery  = A1;  // Potenciometro bateria

// --- Estrutura de categoria ---
struct Category {
  const char* name;
  const char* words[5];
  int numWords;
};

// --- CATEGORIAS E PALAVRAS (7 categorias x 5 palavras = 35) ---
Category categories[] = {
  // Categoria 0
  {"Necessidades", {"Eu quero", "Comer", "Beber", "Banheiro", "Dormir"}, 5},
  // Categoria 1
  {"Sentimentos",  {"Feliz", "Triste", "Bravo", "Calmo", "Medo"},       5},
  // Categoria 2
  {"Acoes",        {"Brincar", "Ajuda", "Sair", "Parar", "Ir"},         5},
  // Categoria 3
  {"Comidas",      {"Agua", "Suco", "Leite", "Pao", "Fruta"},           5},
  // Categoria 4
  {"Lugares",      {"Casa", "Escola", "Parque", "Medico", "Banho"},      5},
  // Categoria 5
  {"Pessoas",      {"Mamae", "Papai", "Vovo", "Professor", "Amigo"},     5},
  // Categoria 6
  {"Saude",        {"Doi", "Enjoo", "Frio", "Calor", "Cansado"},        5}
};

const int NUM_CATEGORIES = sizeof(categories) / sizeof(categories[0]);

// --- Tons para simulacao (7 categorias x 5 palavras = 35 tons) ---
const int tones[] = {
  262, 294, 330, 349, 392,        // Necessidades
  440, 494, 523, 587, 659,        // Sentimentos
  698, 784, 880, 988, 1047,       // Acoes
  1100, 1175, 1250, 1320, 1400,   // Comidas
  300, 350, 400, 450, 500,        // Lugares
  550, 600, 650, 700, 750,        // Pessoas
  800, 850, 900, 950, 1000        // Saude
};

// --- Tempos (ms) ---
const unsigned long DEBOUNCE_DELAY   = 250;
const unsigned long LONG_PRESS_TIME  = 800;
const unsigned long SLEEP_TIMEOUT    = 120000;  // 2 minutos
const unsigned long VOLUME_INTERVAL  = 500;
const unsigned long BATTERY_INTERVAL = 10000;
const int VIBRATE_MS    = 60;
const int PHRASE_DELAY  = 1300;

// --- Frase composta ---
const int MAX_PHRASE = 5;
struct PhraseWord {
  byte cat;
  byte word;
};
PhraseWord phraseBuffer[MAX_PHRASE];
int phraseCount = 0;

// --- Estado ---
int catIndex  = 0;
int wordIndex = 0;
int volume    = 20;
int batteryPercent = 100;

// --- Temporizacao ---
unsigned long lastButtonTime   = 0;
unsigned long lastVolumeTime   = 0;
unsigned long lastBatteryTime  = 0;
unsigned long lastActivityTime = 0;

// --- Botao FALAR (long press) ---
bool speakBtnPrev = false;
unsigned long speakPressStart = 0;

// --- Sleep ---
bool isSleeping = false;

// --- Caracteres customizados LCD ---
byte charArrow[8]   = {0x00, 0x04, 0x06, 0x1F, 0x1F, 0x06, 0x04, 0x00};
byte charSpeaker[8] = {0x01, 0x03, 0x0F, 0x0F, 0x0F, 0x03, 0x01, 0x00};
byte charBatFull[8] = {0x0E, 0x1F, 0x1F, 0x1F, 0x1F, 0x1F, 0x1F, 0x1F};
byte charBatMid[8]  = {0x0E, 0x11, 0x11, 0x1F, 0x1F, 0x1F, 0x1F, 0x1F};
byte charBatLow[8]  = {0x0E, 0x11, 0x11, 0x11, 0x11, 0x11, 0x1F, 0x1F};
byte charPhrase[8]  = {0x00, 0x0A, 0x1F, 0x1F, 0x0E, 0x04, 0x00, 0x00};

// ===================== FUNCOES AUXILIARES =====================

// Stub para auto-detect I2C (no Wokwi sempre retorna 0x27)
byte detectI2C() {
  Wire.begin();
  byte addrs[] = {0x27, 0x3F, 0x20, 0x38};
  for (byte i = 0; i < 4; i++) {
    Wire.beginTransmission(addrs[i]);
    if (Wire.endTransmission() == 0) {
      Serial.print(F("I2C encontrado: 0x"));
      Serial.println(addrs[i], HEX);
      return addrs[i];
    }
  }
  Serial.println(F("I2C nao detectado, usando 0x27"));
  return 0x27;
}

void vibrate() {
  digitalWrite(pinVibrate, HIGH);
  delay(VIBRATE_MS);
  digitalWrite(pinVibrate, LOW);
}

bool anyButtonPressed() {
  return (digitalRead(btnCatUp) == LOW ||
          digitalRead(btnCatDown) == LOW ||
          digitalRead(btnWordUp) == LOW ||
          digitalRead(btnWordDown) == LOW ||
          digitalRead(btnSpeak) == LOW);
}
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

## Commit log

2026-05-14 v2.0: README completo, case 3D corrigido para impressao, viewer 3D com componentes internos
    - README.md reescrito com documentacao completa do projeto
    - Case 3D: berco bateria simplificado, snap-fit reforçado, labels texto real,
    grade speaker 3mm, pes de borracha, furos ventilacao, motor sem overhang
    - Tampa exportada invertida para impressao sem suportes
    - Viewer 3D: componentes internos visiveis (Arduino, DFPlayer, 18650, TP4056,
    motor, chave, potenciometro) com modo transparente e labels
    [case_voz_autista.scad, exportar_base.scad, exportar_tampa.scad]
2026-05-14 Adiciona apresentacao HTML interativa do projeto
    Apresentacao com 13 slides navegaveis por teclado/touch:
    problema, solucao, funcionalidades, hardware, categorias,
    case 3D, simulacao Wokwi, custo, codigo e trabalhos futuros.
2026-05-28 Adiciona simulador interativo com TTS e melhora apresentacao
    - Simulador HTML completo com Text-to-Speech em portugues
    - LCD virtual, 7 categorias, 35 palavras, frase composta
    - Web Audio API para tons de buzzer, Web Speech API para TTS
    - Balao de fala, animacao de ondas, indicador de status TTS
    - Apresentacao com layout melhorado (gradientes, animacoes)
2026-05-28 Adiciona orcamento detalhado e circuito esquematico real
    - Slide de custo na apresentacao com BOM completo (qtd, spec, unit, total)
    - Circuito esquematico SVG completo no manual de montagem (etapa 6)
    - Diagrama baseado na simulacao Wokwi com pinagem identica
    - Tabela de pinos expandida com cores dos fios e notas tecnicas
    - Etapas renumeradas (6=circuito, 7=montagem final, 8=teste)
2026-05-28 Corrige erros no manual de montagem: SD card, cores de fios e descricao do circuito
    - Remove slot SD externo do case (microSD vai dentro do DFPlayer Mini)
    - Troca labels SD por Speaker nas vistas do case base e 3D
    - Adiciona seta visual Insere no DFPlayer no diagrama de materiais
    - Corrige cor do fio A0 de Laranja para Roxo (conforme Wokwi)
    - Corrige cor do fio A4 de Roxo para Verde (conforme Wokwi)
    - Reescreve descricao do circuito para diferenciar hardware real vs simulacao
    - Atualiza checklist: especifica inserir microSD no DFPlayer Mini
    - Remove comentario HTML obsoleto
2026-06-05 Adiciona roadmap no index e pagina de entrega Etapa 2
    - index.html: nova secao Roadmap com 3 colunas (curto/medio/longo prazo)
    + bloco de entregaveis do grupo + status strip. Botao "Roadmap" no hero.
    - entrega_etapa2.html: documento HTML imprimivel da Atividade 02
    (evidencias de progresso + roadmap, com CSS de print A4).
    - Remove screenshots temporarios de validacao acidentalmente commitados.
    - .gitignore: ignora _*.png e _*.jpg para evitar reincidencia.
2026-06-05 Trigger Pages deploy
    Forca novo build apos mudanca de Source de gh-pages para main.
2026-06-05 Alinha cores do viewer 3D ao manual de montagem
    - Arduino PCB: verde -> azul navy oficial (manual usa #0ea5e9)
    - DFPlayer: cor vermelha #b91c1c (igual ao manual)
    - Motor de vibracao: cobre -> cinza com centro escuro
    - Adiciona placeholder transparente do speaker no plano da tampa
    para que apareca na vista de "Componentes Internos"
    - Painel de dimensoes: lista os componentes com badges coloridos
    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
2026-06-05 Case v2.0 pronto para impressao: clipes, suporte do speaker e selo
    Adiciona o que faltava para a montagem real funcionar sem cola/fita:
    - speaker_mount(): anel interno de 40mm + labio + corte para fio,
    alinhado com a grade externa da tampa
    - dfplayer_clips(): 2 clipes em L que prendem a PCB do DFPlayer pela
    lateral (libera o slot SD que sai pela parede direita)
    - tp4056_clips(): 2 clipes que seguram a PCB pequena do carregador
    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
    [case_voz_autista.scad]
2026-06-05 Viewer 3D reflete as novas estruturas do case .scad
    - Clipes do DFPlayer (2 laterais em L com labio) na vista interna
    - Clipes do TP4056 (2 N/S com labio)
    - Suporte (anel) do speaker 40mm na tampa, alinhado com a grade
    - Selo "Voz Autista v2.0" como overlay no fundo externo, visivel
    quando a camera olha por baixo
    - Painel de dimensoes lista config de impressao (PLA/PETG, 120g, 9h)
2026-06-11 v3.0: case em cunha, circuito revisado e viewer 3D do circuito
    - Case v3.0 (case_voz_autista_v3.scad): 150x100x40-48mm, LCD a 12 graus,
    botoes 2+2+1 com aneis tateis, bateria com tampa de troca no fundo,
    speaker no fundo, orelhas p/ cordao + exportadores e CHANGELOG_V3
    - Circuito: divisor da bateria 100k/33k com ref interna 1.1V (corrige
    leitura ratiometrica), divisor 1k/2k no RX do DFPlayer, 470uF+100nF,
    BUSY->D8 (fim real do audio nas frases), boost MT3608 no rail 5V
    - Wokwi: driver 2N2222 real, divisor real da bateria, labels PT
    - Manual visual e guia reescritos para v3.0
    - Novo viewer 3D interativo do circuito (Three.js)
    [case_voz_autista_v3.scad, exportar_base.scad, exportar_tampa.scad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]
2026-06-11 Viewer 3D do case reflete o v3.0 e index ganha card do circuito 3D
    - visualizar_case_3d.html: geometria em cunha 150x100x40-48, LCD na rampa
    de 12 graus, botoes 2+2+1 (FALAR maior), bateria vertical c/ tampa no
    fundo, speaker no fundo, MT3608, orelhas de cordao, chave recuada
    - index.html: titulo/hero v3.0, card do case atualizado e novo card
    para o viewer 3D do circuito
2026-06-11 Manual de montagem detalhado: 7 etapas passo a passo no lugar do checklist unico
2026-06-18 Apresentacao final em slides: fotos do time, demo do simulador e case 3D
    - Deck de slides (apresentacao_final.html) ligado ao index.html
    - Quem somos com fotos reais do time (img/); Joao como Lider/Programador
    - Slide de demonstracao ao vivo embutindo o simulador (simulador.html)
    - case_3d/case_preview.html: modelo 3D so do case, fundo branco, estatico, camera de cima
2026-06-25 Apresentacao: 4 slides novos, botao de tela cheia e ajustes de dados
    - Novos slides: Circuito real, engenharia v2->v3 (5 bugs), validacao
    sem hardware (Wokwi/simulador) e design para o usuario autista
    - Botao de tela cheia no topo (sincronizado com a tecla F)
    - Autonomia reconciliada para ~14h continuo (~115mA no rail 5V)
    - Custo: linha do boost MT3608 explicitada mantendo total ~R$128
    - Slide do time sem o aviso de placeholder
2026-06-25 Apresentacao: novo slide Como o usuario opera (passo a passo)
    - Slide de fluxo de operacao em 6 passos, adaptado da apresentacao
    antiga para o padrao visual do deck final
    - Inserido apos Como se usa, na secao do produto
    - Versao atualizada para v3.0 e LCD no estado de frase falando
